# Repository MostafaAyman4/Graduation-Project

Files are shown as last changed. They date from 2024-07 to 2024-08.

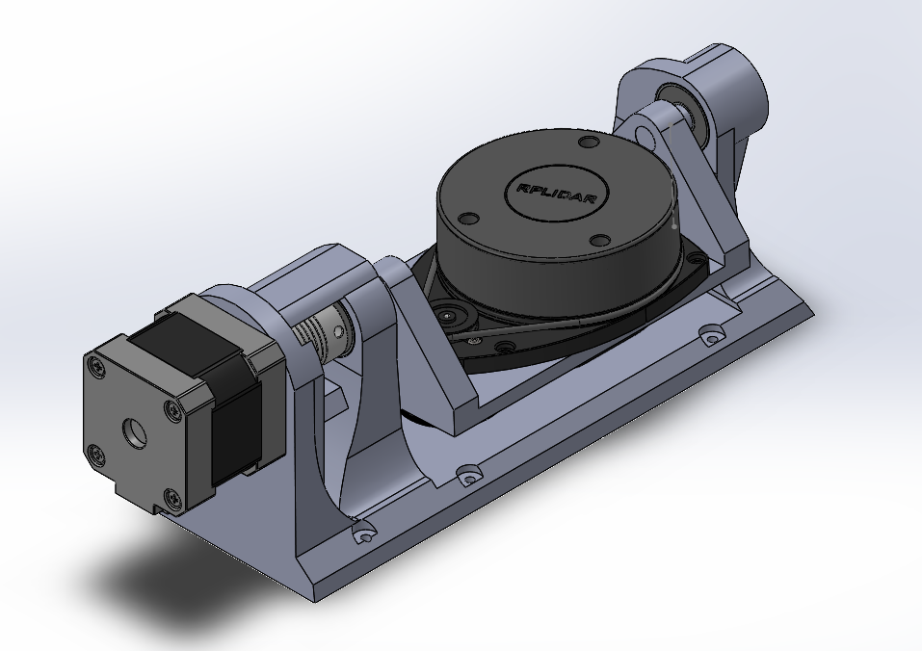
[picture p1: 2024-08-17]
3D designing/3D Lidar/Photos/ASSEMBLY_3D_LIDAR.png

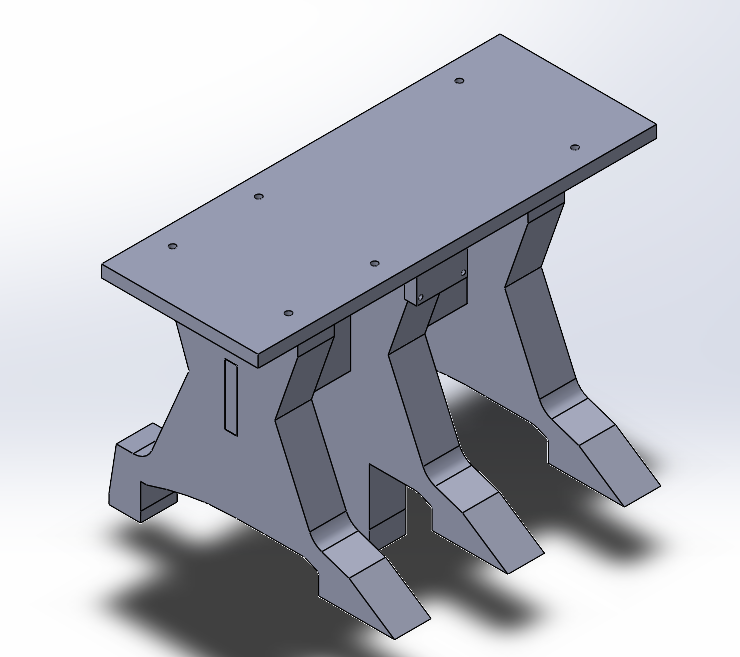
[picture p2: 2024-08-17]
3D designing/3D Lidar Support/Photos/ASSEMBLY_LIDAR_SUPPORT.png

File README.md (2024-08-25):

# Self-Driving Car
/*******************************************************************************************

************************** THIS REPO CONTAINS ONLY MY PARTS *************************

********************************************************************************************/

We have achieved Level 3 on the automotive scale, having successfully passed the first four levels test stages:



Level 0: A pretty simple phase where we manually controlled the car using a mobile application.

Level 1: Implemented an anti-collision using ultrasonic sensors System to monitor the surrounding environment.

Level 2: The car began to take control of its speed and direction autonomously, implementing lane assistance.

Level 3: The car can now drive itself entirely, determining its destination from the user’s application and using built-in GPS for navigation. It processes a significant amount of data to drive autonomously.

Project Specializations :

Project diagram

 1. Embedded systems
 2. AI
 3. Circuit design
 4. PCB design and manufacturing
 5. 3D design

-I was responsible for these parts

    •	Project architecture
   
    •	All ARM (M3) cores connected together with CAN bus
   
       1.	Motion layer (back motors and steering system with PID controller)
       
       2.	Mapping layer (8 ultrasonic sensor runs 4 by 4 parallel)
       
       3.	Lidar layer (I transform 2D lidar to Work as 3D lidar by I mechanism and codes with equations)
       
    •	Main core (I wrote the MCAL Layer and collaborated with Nagham and Noran to design the code’s architecture and algorithms)
   
    •	Circuit diagram, PCB design and manufacturing with solder mask
   
    •	3D designing

   -Team Members 
   
     -Mostafa Prince
     
     -Nagham Nasser
     
     -Noran Nabil
     
     -Rodina Mohamed

   ALL DATA IN THIS REPO ARE OPEN SOURCE, FEEL FREE TO USE IT TO SHAPE THE NEW FUTURE
   
   CONTACT ME IF U NEED ANY HELP @ mostafaaymen109@gmail.com

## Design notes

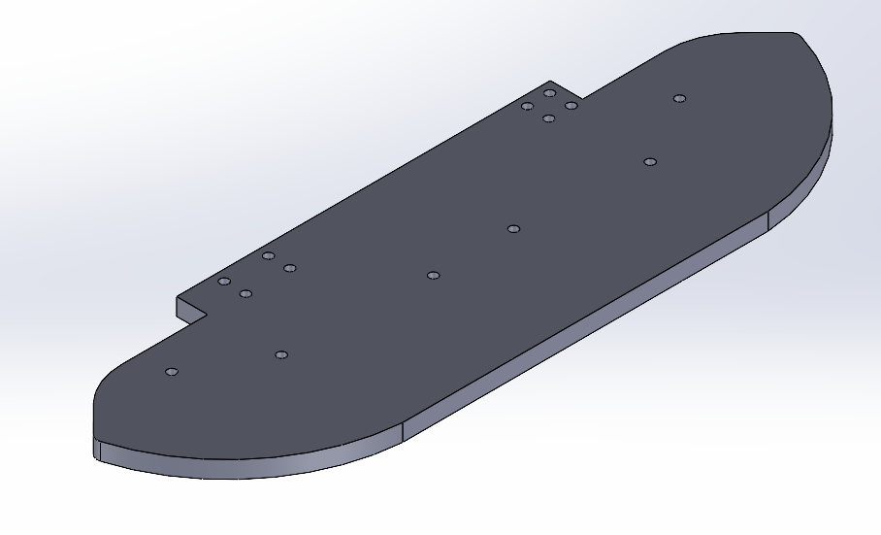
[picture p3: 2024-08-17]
3D designing/Main body/Photos/AS.png

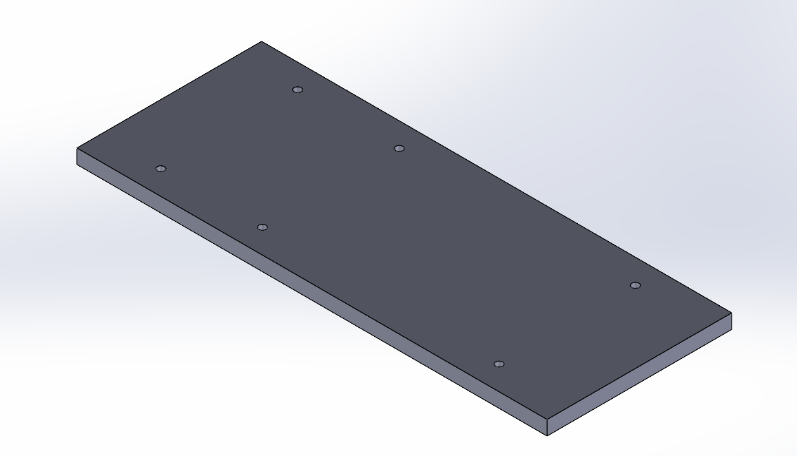
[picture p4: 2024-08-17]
3D designing/3D Lidar Support/Photos/Screenshot 2024-07-12 020455.png

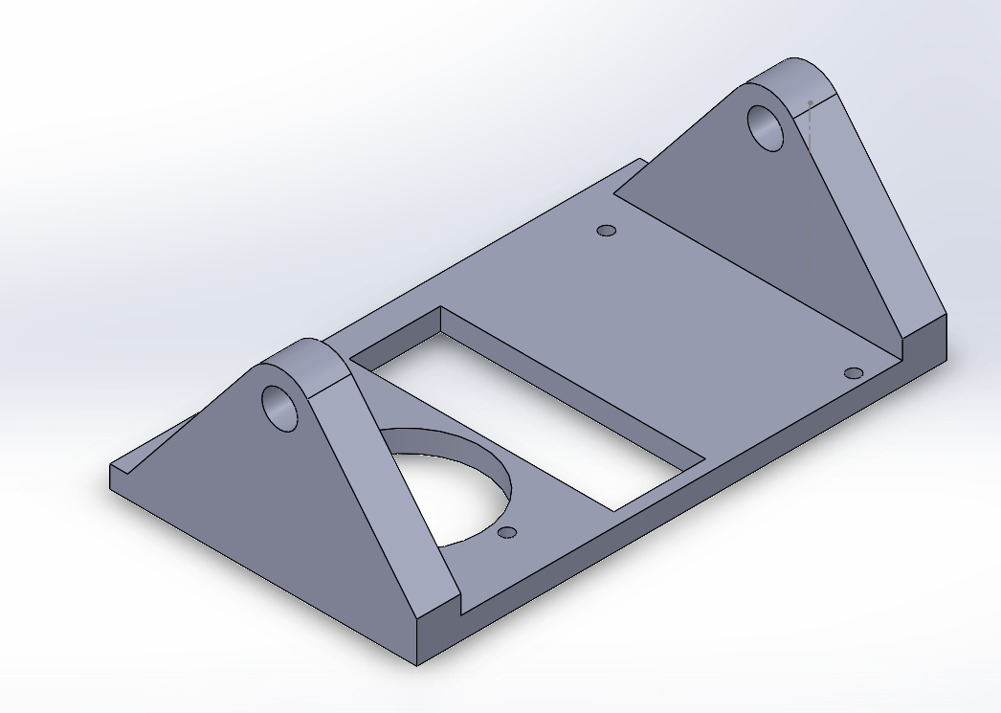
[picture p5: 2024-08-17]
3D designing/3D Lidar/Photos/Screenshot 2024-07-12 014340.png

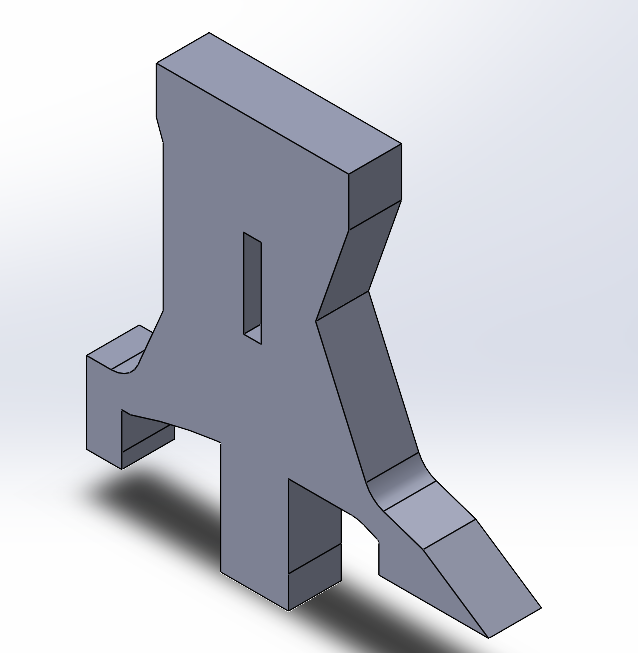
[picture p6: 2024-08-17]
3D designing/3D Lidar Support/Photos/Screenshot 2024-07-12 020410.png

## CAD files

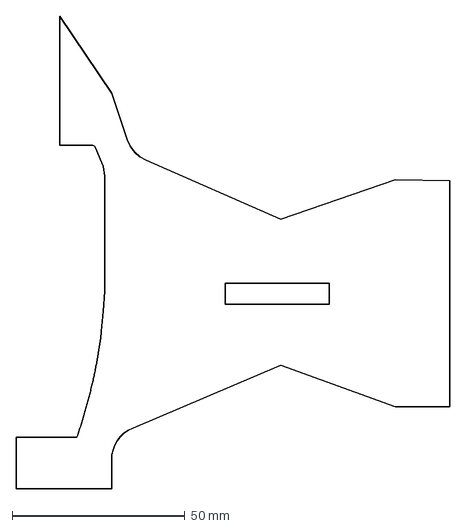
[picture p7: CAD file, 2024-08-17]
3D designing/3D Lidar Support/DXF FILES/LEFT_SUPPORT.dxf
125.6 x 136.9 mm

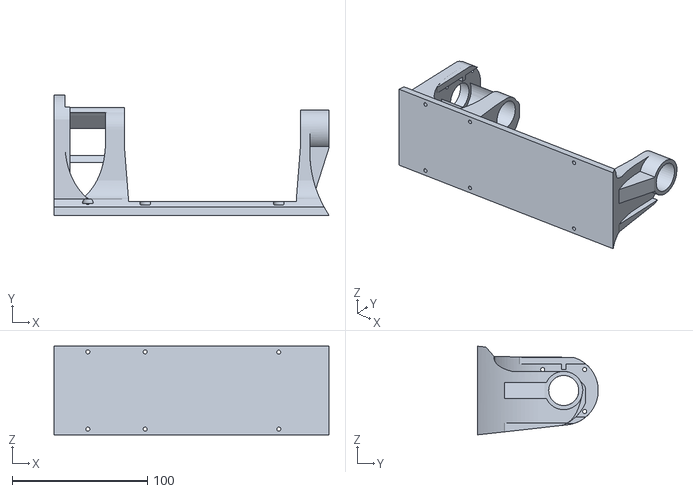
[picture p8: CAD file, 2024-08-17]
3D designing/3D Lidar/PLA Printing/BASE.stl
203.1 x 89.0 x 65.5

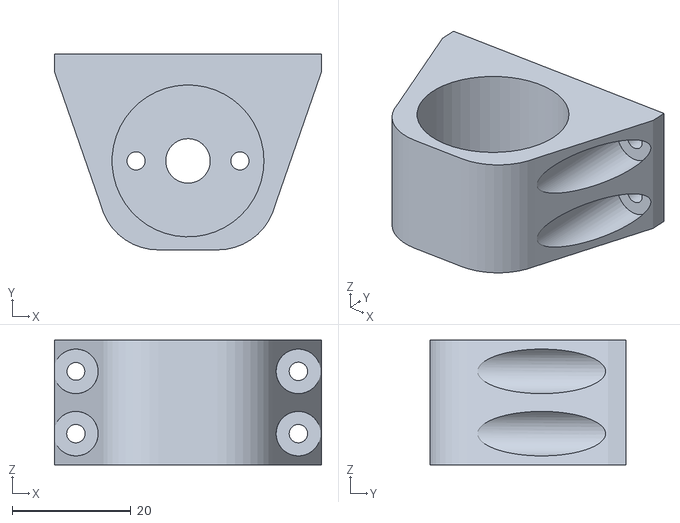
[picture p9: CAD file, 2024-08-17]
3D designing/Back Motors Holder/STL Files/MOTOR_HOLDER--V2.STL
45.0 x 33.0 x 21.0

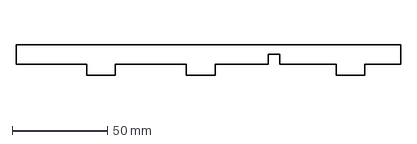
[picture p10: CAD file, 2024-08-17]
3D designing/Main body/DXF files/Supports.dxf
201.4 x 15.8 mm

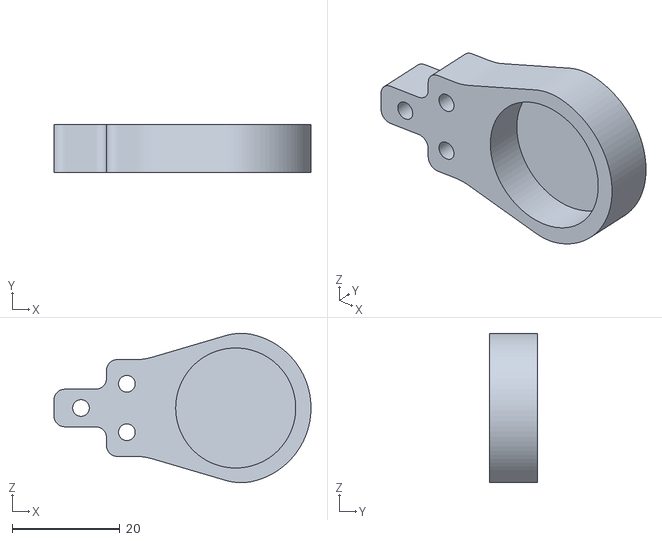
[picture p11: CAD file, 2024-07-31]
3D designing/Steering System/PLA Printing/bearing_support.stl
47.8 x 9.00 x 27.7

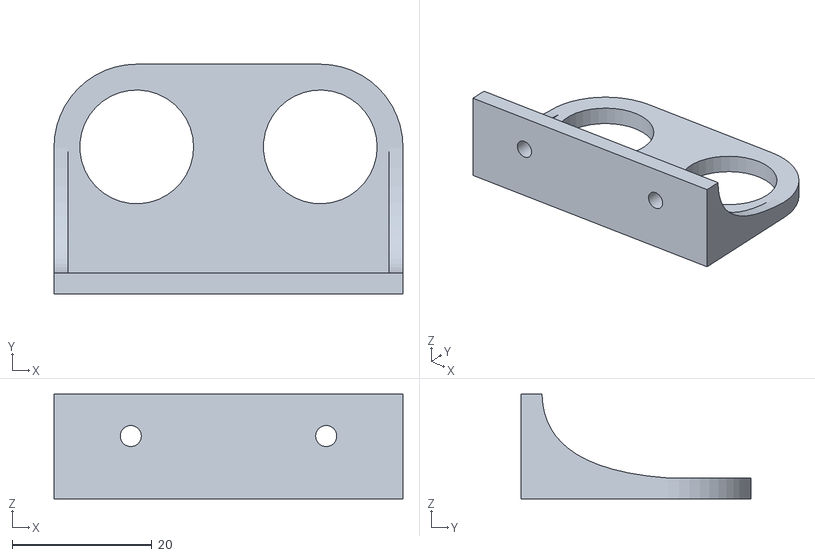
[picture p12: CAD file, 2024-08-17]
3D designing/Ultrasonic Holder/STL Files/ULTRASONIC HOLDER-parody 6 pieces.STL
50.0 x 32.9 x 15.0

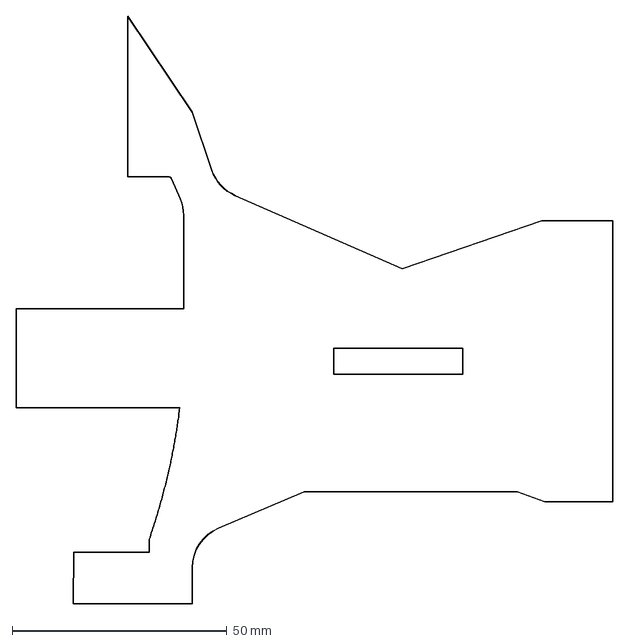
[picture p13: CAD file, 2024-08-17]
3D designing/3D Lidar Support/DXF FILES/Center_support.dxf
139.0 x 136.9 mm

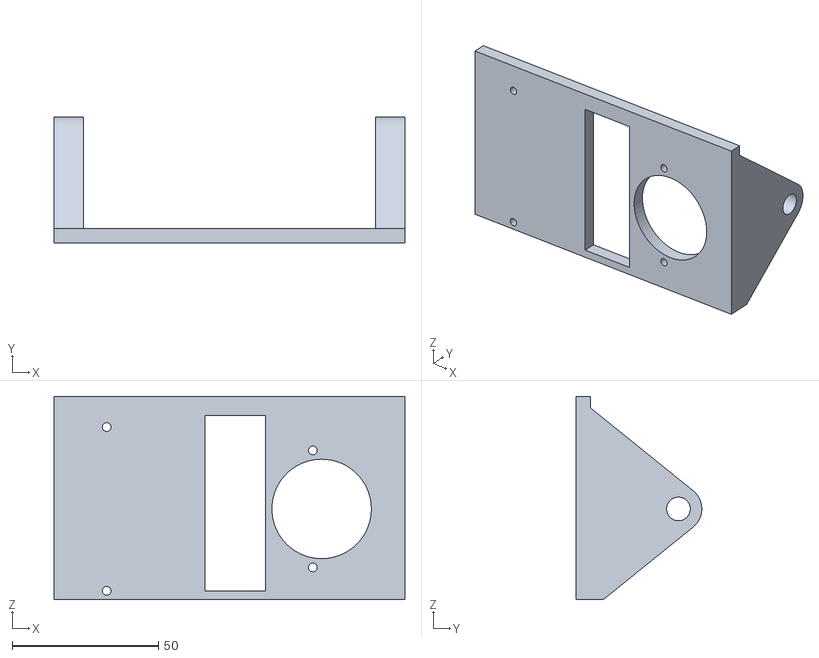
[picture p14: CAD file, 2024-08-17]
3D designing/3D Lidar/PLA Printing/moving part.stl
120.0 x 43.0 x 69.5

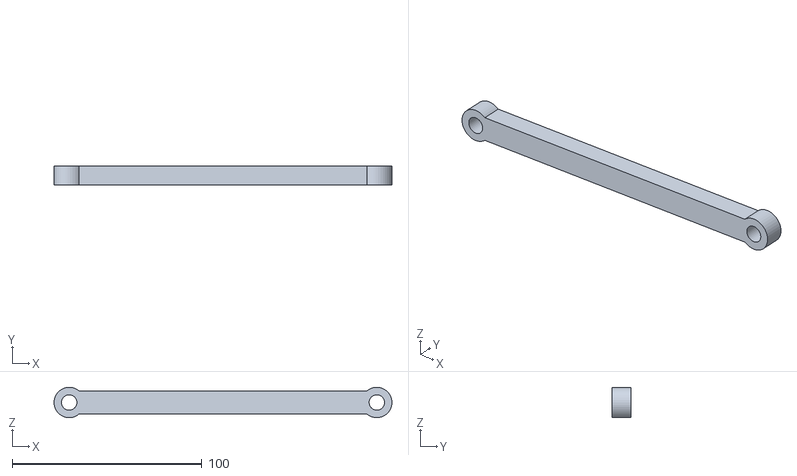
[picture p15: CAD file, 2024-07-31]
3D designing/Steering System/PLA Printing/steering_connector.stl
178.0 x 10.0 x 16.0

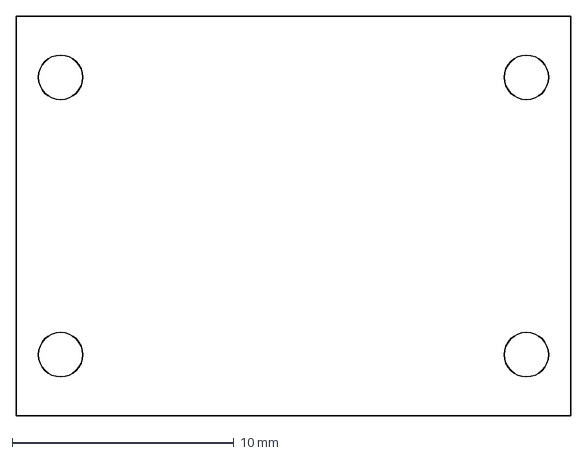
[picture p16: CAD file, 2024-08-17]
3D designing/3D Lidar Support/DXF FILES/Camera_Holder.dxf
25.0 x 18.0 mm

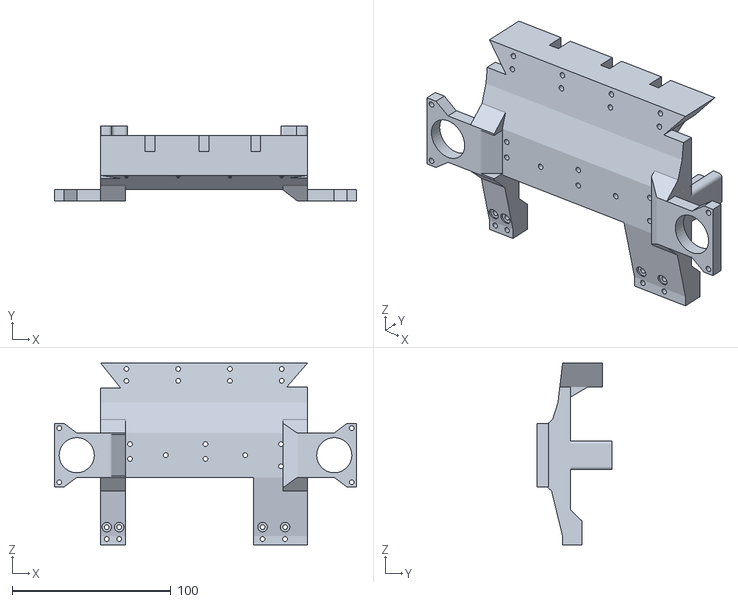
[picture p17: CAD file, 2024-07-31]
3D designing/Steering System/PLA Printing/BASE_V2_top.stl
190.0 x 47.0 x 114.5

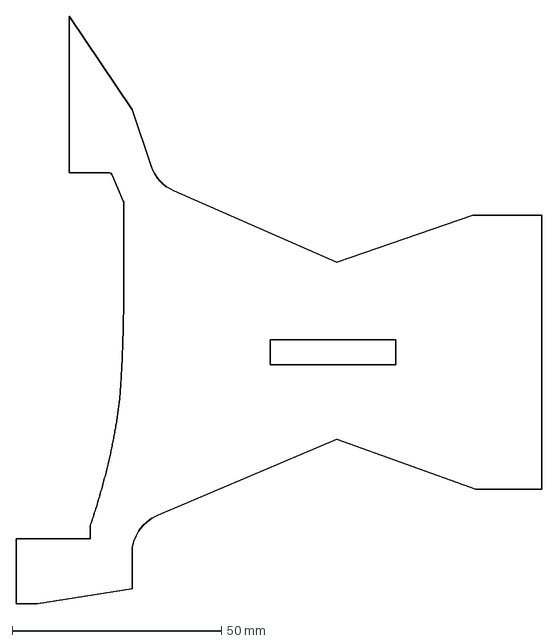
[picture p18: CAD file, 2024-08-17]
3D designing/3D Lidar Support/DXF FILES/RIGHT_SUPPORT.dxf
125.7 x 140.5 mm

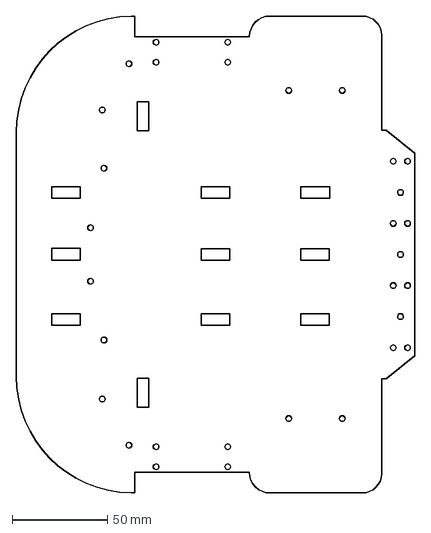
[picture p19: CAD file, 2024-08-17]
3D designing/Main body/DXF files/Base_LASER_CUT_2.dxf
208.9 x 250.0 mm

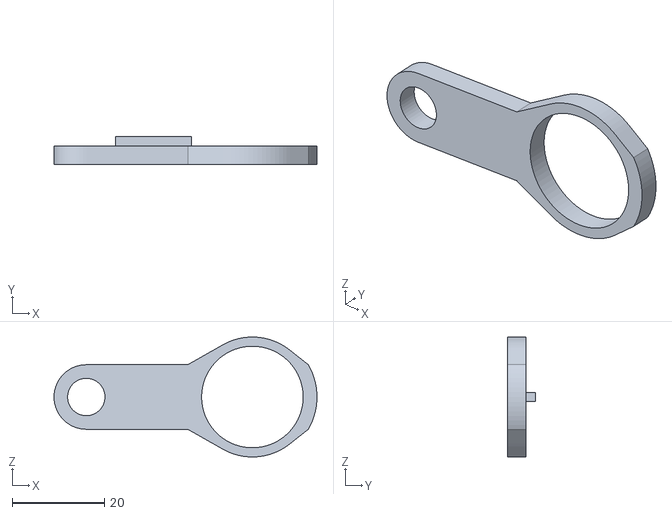
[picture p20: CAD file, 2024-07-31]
3D designing/Steering System/PLA Printing/wheel_connector_half.stl
57.0 x 6.00 x 26.0

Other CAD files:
3D designing/Main body/DXF files/base_laser_cut_1 v1.dxf
3D designing/3D Lidar Support/DXF FILES/Lidar_Base.dxf
3D designing/Main body/DXF files/test_dxf.dxf
3D designing/Steering System/PLA Printing/wheel_connector.stl
3D designing/3D Lidar Support/DXF FILES/Lidar_connector.dxf
3D designing/Main body/DXF files/Support_2.dxf
3D designing/Main body/DXF files/base_laser_cut_1 v0.dxf
3D designing/Steering System/PLA Printing/wheel holder.stl

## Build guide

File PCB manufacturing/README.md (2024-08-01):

# Manufacturing of PCBS with Solder Mask
   IMG_7378 (1)

Printed Circuit Boards (PCBs) are essential components in electronic devices, providing the necessary platform for mounting and connecting electronic components. One of the DIY-friendly methods for PCB manufacturing is the toner transfer method. This repo outlines the process of manufacturing PCBs using the toner transfer technique, highlighting each step involved.
1. Design Preparation

1.1 Schematic Capture

The process begins with designing the circuit schematic using Electronic Design Automation (EDA) software we use EASYEDA. The schematic is a blueprint of the electrical connections and components.
main_Schematic

1.2 Layout Design

The schematic is converted into a PCB layout using the same EDA software. This layout includes the placement of components and routing of copper traces. Once finalized, the layout is printed onto glossy paper or special toner transfer paper using a laser printer.
2. Substrate Preparation

PCB_PCB_Graduation_project_Lega_2_2024-07-15-1

2.1 Cleaning

A copper-clad board, typically made of fiberglass with a layer of copper, is used as the substrate. The copper surface is thoroughly cleaned using fine steel wool or abrasive pads to remove any oxidation and contaminants, ensuring good adhesion of the toner.

3. Toner Transfer
3.1 Aligning and Fixing
The printed design is placed toner-side down onto the cleaned copper-clad board. It is essential to align the design correctly to ensure accurate transfer.



3.2 Toner Transfer
   
Using Toner or Acetone to wet the paper with copper layer and with some pressure the ink stick to the copper
 
3.3 Removing the Paper

the paper is soaked in water to soften it. The paper is then carefully removed, leaving the toner on the copper, which now acts as a resist for the etching process.



4. Etching
   
The board is submerged in an etching solution, typically ferric chloride or ammonium persulfate. The solution removes the exposed copper, leaving only the copper traces protected by the toner. This process is done in a well-ventilated area, using appropriate safety measures.
  


6. Toner Removal
   
After etching, the toner is removed using acetone or isopropyl alcohol, revealing the copper traces that form the circuit.




8. Drilling
A drill press or a handheld drill with fine drill bits is used to create holes for through-hole components and vias. Precision is crucial to ensure proper component placement.

9. Solder Mask Application
Applying a solder mask to a printed circuit board (PCB) is an essential step in ensuring the board’s durability and reliability. A solder mask protects the copper traces from oxidation, prevents solder bridges during soldering, and improves the overall appearance of the PCB. One effective method for applying a solder mask is using a silk screen frame. This report provides a step-by-step guide on how to create and apply a solder mask using this technique.
Materials and Tools Needed
•	Cleaned PCB with exposed copper traces
•	Silk screen frame with fine mesh
•	Solder mask ink (e.g., UV curable or thermal curing solder mask)
•	Squeegee
•	Transparent film with the solder mask pattern (positive or negative image)
•	UV light source (for UV curable masks)
•	Developer solution (if using a photoimageable solder mask)
•	Curing oven (if using thermal curing solder mask)
•	Protective gloves and goggles
•	Isopropyl alcohol or acetone
•	Fine abrasive pad or steel wool (for initial cleaning)
Step-by-Step Process
1. Preparing the PCB
1.	Cleaning: Ensure the PCB is clean and free of any contaminants. Use a fine abrasive pad or steel wool to scrub the copper surface lightly. Clean the board with isopropyl alcohol or acetone and let it dry completely.
2. Preparing the Silk Screen
1.	Design Preparation: Print the solder mask pattern onto a transparent film. This pattern should expose areas where solder will be applied and protect the rest of the board.
 
  


2.	Setting Up the Screen: Attach the transparent film to the silk screen frame. Ensure that the film is aligned correctly with the PCB layout. The screen should have a fine mesh suitable for detailed work.

  


3. Applying the Solder Mask
1.	Applying the Solder Mask Ink: Pour a small amount of solder mask ink onto the silk screen.

  	 

3.	Spreading the Ink: Using a squeegee, spread the solder mask ink evenly across the screen. The ink will pass through the mesh in areas not blocked by the pattern, transferring the solder mask design onto the PCB.



4.	Positioning the PCB: Place the cleaned PCB under the silk screen frame. Ensure it is properly aligned with the pattern on the transparent film.

 

5.	Checking Coverage: Carefully lift the silk screen frame and inspect the PCB to ensure the solder mask has been applied correctly. All areas that need to be protected should be covered with the solder mask ink.
4. Curing the Solder Mask
1.	UV Curable Solder Mask:
o	Exposure: Place the PCB under a UV light source, exposing it for the recommended amount of time specified by the solder mask manufacturer.



o	Developing: If using a photoimageable solder mask, immerse the PCB in the developer solution to remove unexposed areas, revealing the solder mask pattern.
3.	Thermal Curing Solder Mask:
o	Curing: Place the PCB in a curing oven and bake it at the temperature and duration specified by the solder mask manufacturer.
5. Final Inspection and Touch-Up
1.	Inspection: Inspect the cured solder mask for any defects or areas where coverage is inadequate. Use a magnifying glass or microscope for detailed inspection.  
2.	Touch-Up: If necessary, use a small brush to apply additional solder mask ink to any missed spots and cure as needed.
6. Cleaning and Finishing
1.	Cleaning: Clean the PCB with isopropyl alcohol or acetone to remove any residual developer or uncured ink.
2.	Finishing: Lightly sand the solder mask surface to smooth out any rough edges or uneven areas.

8. Assembly
8.1 Component Placement
Components are manually placed on the board according to the design. 
8.2 Soldering
Components are soldered using a soldering iron. For SMD components, a reflow oven or hot air gun may be used to melt solder paste applied during placement.



9. Testing and Inspection

9.1 Visual Inspection
A through visual inspection is conducted to check for any visible defects such as solder bridges, misaligned components, or incomplete etching.

9.2 Electrical Testing
Basic electrical tests are performed to ensure continuity and correct connections. Multimeters or simple test circuits can be used to verify functionality.
 


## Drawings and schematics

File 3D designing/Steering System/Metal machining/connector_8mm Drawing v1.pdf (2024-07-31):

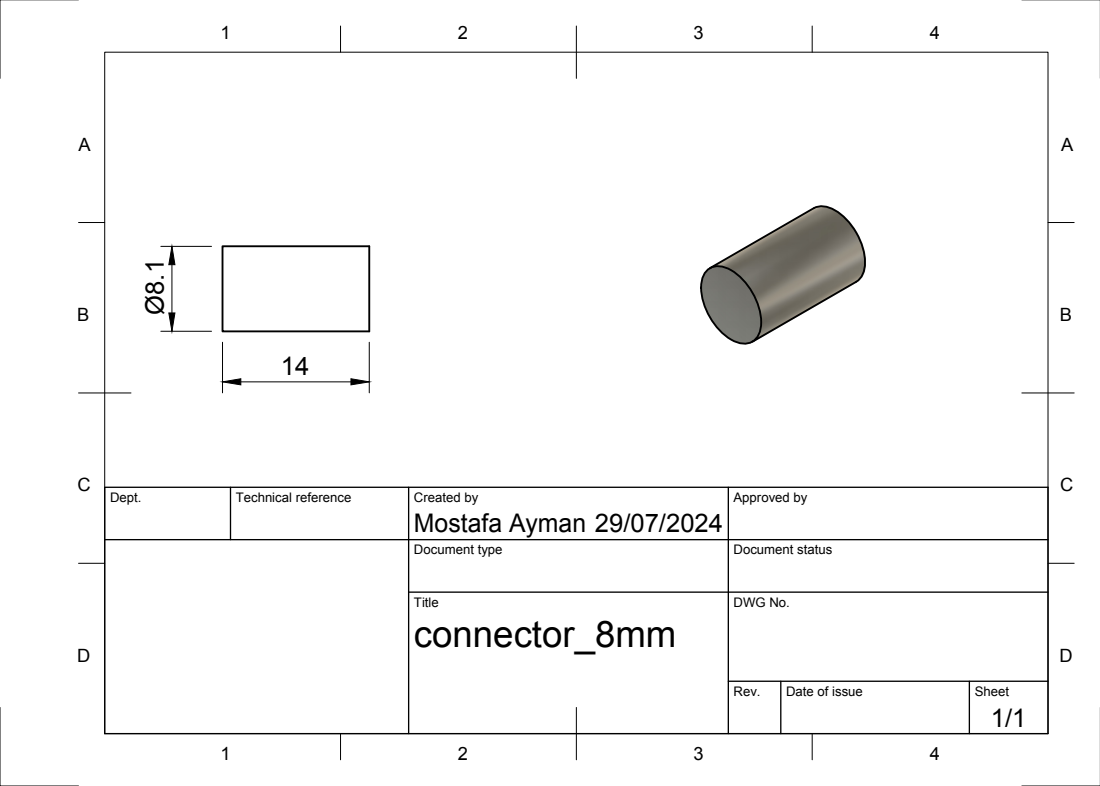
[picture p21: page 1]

Dept. | Technical reference | Created by Mostafa Ayman 29/07/2024 | Approved by

Document type | Document status

Title connector_8mm | DWG No.

Rev. | Date of issue | Sheet 1/1

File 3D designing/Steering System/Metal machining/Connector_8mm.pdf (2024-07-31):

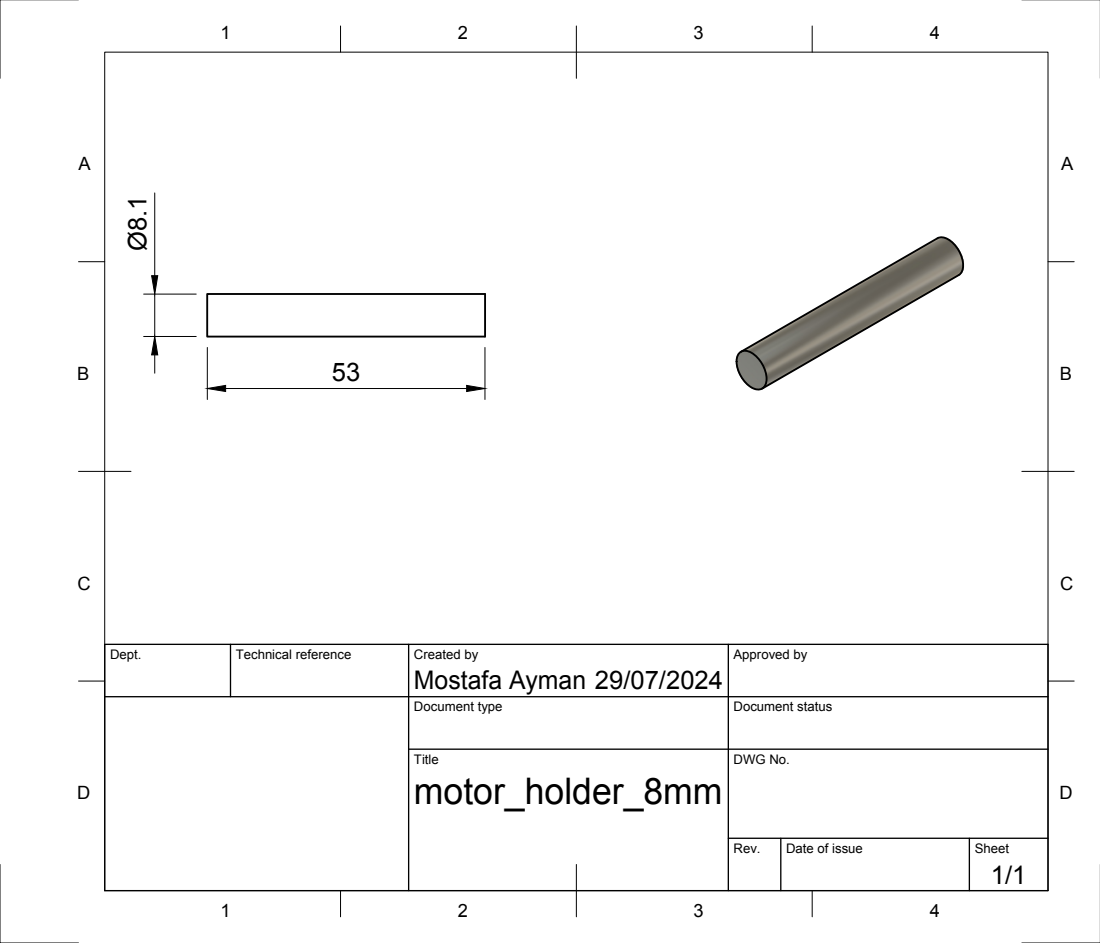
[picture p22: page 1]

Dept. | Technical reference | Created by Mostafa Ayman 29/07/2024 | Approved by

Document type | Document status

Title motor_holder_8mm | DWG No.

Rev. | Date of issue | Sheet 1/1

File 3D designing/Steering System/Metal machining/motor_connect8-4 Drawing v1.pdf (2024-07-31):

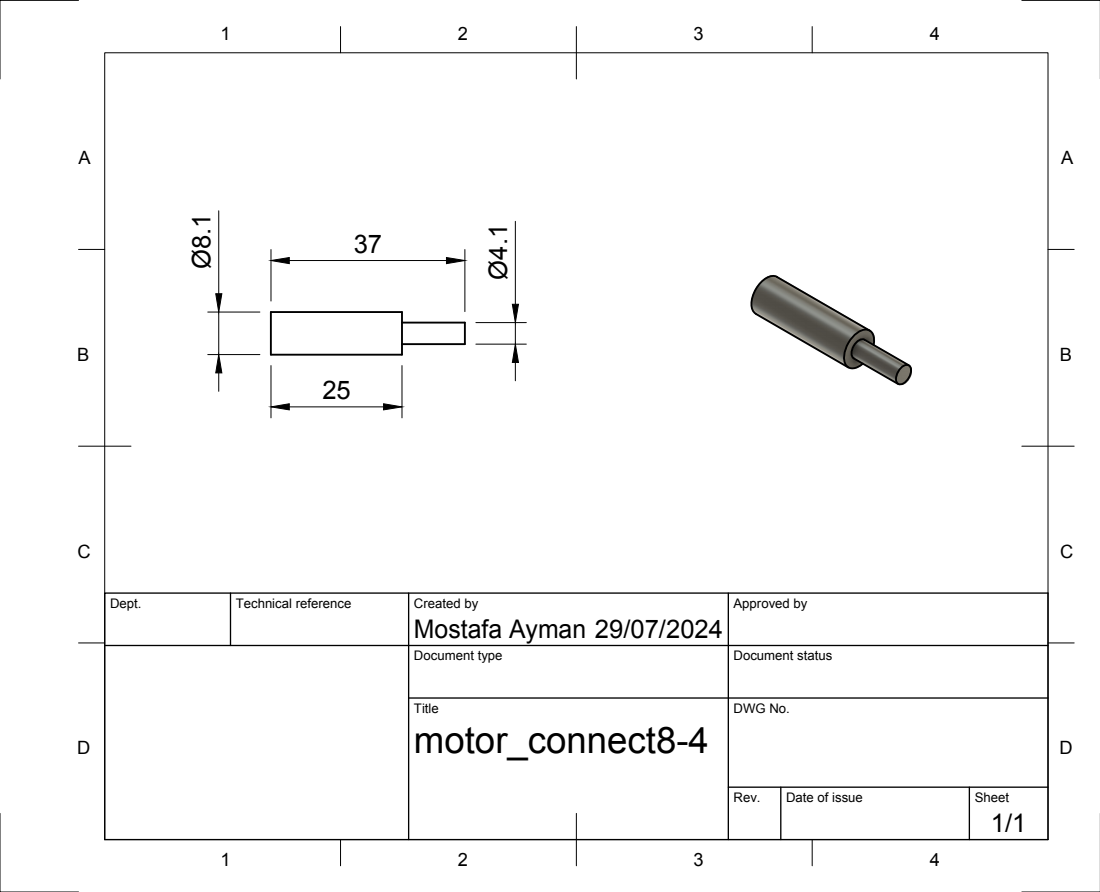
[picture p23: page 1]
Mostafa Ayman Ø8.1

Dept. | Technical reference | Created by 29/07/2024 | Approved by

Document type | Document status

Title motor_connect8-4 | DWG No.

Rev. | Date of issue | Sheet 1/1

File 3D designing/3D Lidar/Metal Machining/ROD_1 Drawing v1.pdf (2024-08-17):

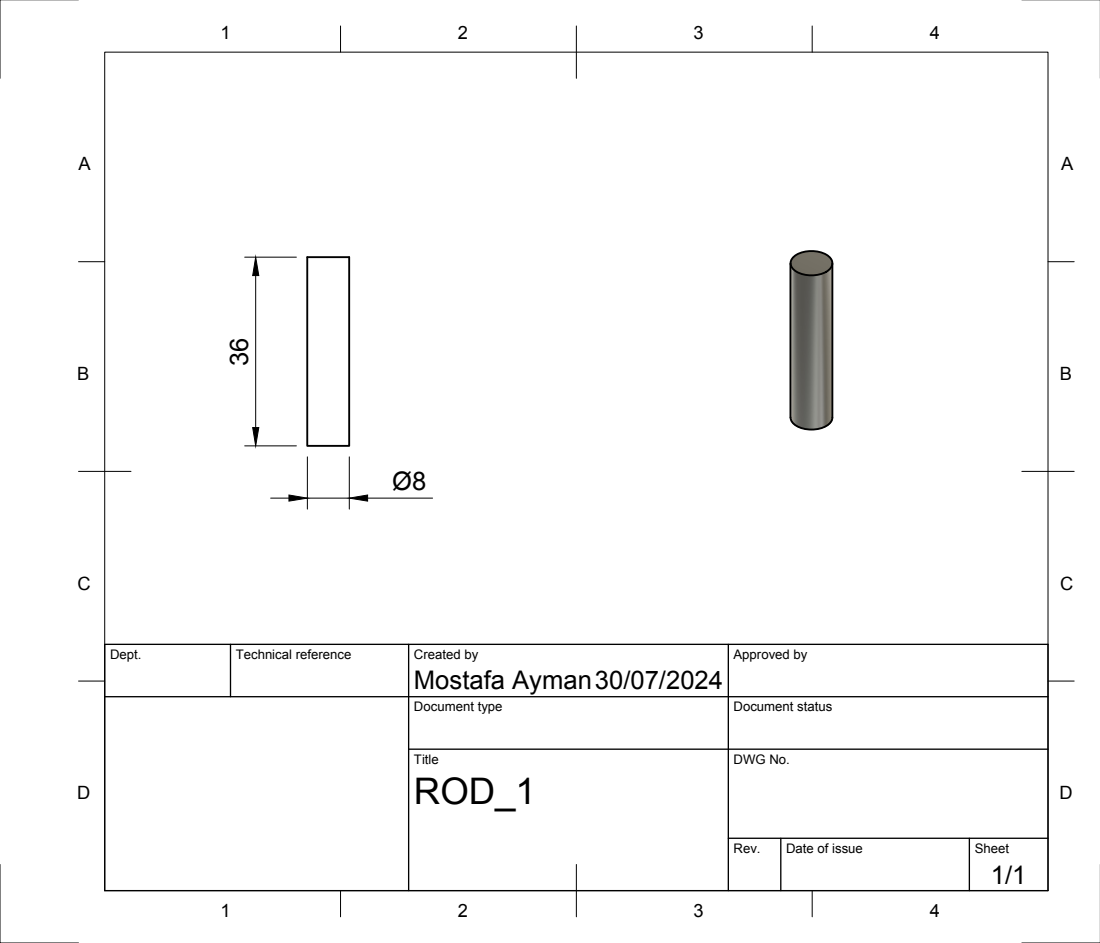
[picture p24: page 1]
Mostafa Ayman 36

Dept. | Technical reference | Created by 30/07/2024 | Approved by

Document type | Document status

Title ROD_1 | DWG No.

Rev. | Date of issue | Sheet 1/1

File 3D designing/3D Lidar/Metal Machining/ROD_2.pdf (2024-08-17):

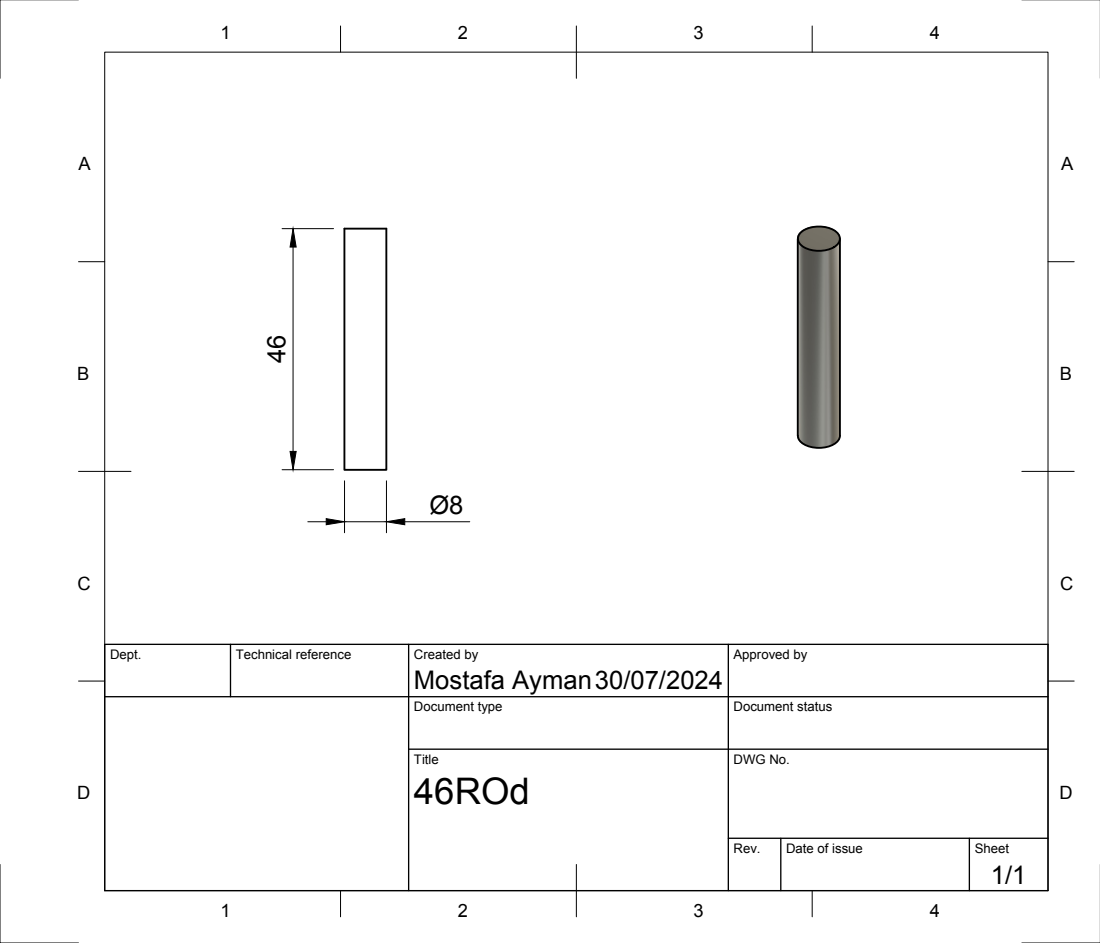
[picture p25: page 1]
Mostafa Ayman 46

Dept. | Technical reference | Created by 30/07/2024 | Approved by

Document type | Document status

Title 46ROd | DWG No.

Rev. | Date of issue | Sheet 1/1

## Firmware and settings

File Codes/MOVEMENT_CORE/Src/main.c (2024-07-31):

/*
 * @file   		main.c
 * @author 		Mostafa Ayman
 * @version		V4.0
 * @MC          STM32F103x
 * @brief       this file has the main program for the motors layer
 */

#include <math.h>
#include "../Inc/LIB/STD_TYPES.h"
#include "../Inc/LIB/BIT_MATH.h"
#include "../Inc/MCAL/RCC/RCC_interface.h"

//#include "../Inc/MCAL/RCC/RCC_private.h"
#include "../Inc/MCAL/DIO/DIO_interface.h"
#include "../Inc/MCAL/SYSTIC/MSYSTICK_interface.h"
#include "../Inc/MCAL/STK/STK_interface.h"

#include "../Inc/MCAL/USART/UART_interface.h"
#include "../Inc/MCAL/CAN/CAN_interface.h"
#include "../Inc/MCAl/GENERAL_PURPOSE_TIMERS/GENRERALTIMERS_interface.h"
//#include "../Inc/MCAl/GENERAL_PURPOSE_TIMERS/GENRERALTIMERS_private.h"
#include "../Inc/MCAL/NVIC/MNVIC_interface.h"

//#include "../Inc/HAL/ULTRASONIC/ULTRASONIC_interface.h"
//#include "../Inc/HAL/ULTRASONIC/ULTRASONIC_config.h"

#include "../Inc/HAL/BACK_MOTORS/BKMOTORS_interface.h"
#include "../Inc/MCAL/EXTI/EXTI_interface.h"
#include "../Inc/HAL/SERVO/SERVO_interface.h"
#if !defined(_SOFT_FP_) && defined(__ARM_FP)
  #warning "FPU is not initialized, but the project is compiling for an FPU. Please initialize the FPU before use."
#endif
/**************************************************************
 * ************ * Macros* ************************
 **************************************************************/
#define TX_PIN			10
#define RX_PIN			11

#define MOTOR_ENCODER_PIN  PA0
///////////////////used in motor movement///////////////////////
#define FORWARD       2
#define BACKWARD      3

#define speed_level_1        130
#define speed_level_2        170
#define speed_level_3		 210
#define speed_level_4		 255

/**************************************************************
 * ************ * Variables* ************************
 **************************************************************/
float init_time=0;
float final_time=0;
float duration_time=0;
float freq;
float average=0;
int index=0;
float deltaT=0;
float v1Filt = 0;
float v1Prev = 0;
float eintegral = 0;
float kp = 4;
float ki = 50;
int desired_speed=100;
int pwr=255;
volatile uint32 DIS_TOTAL_PULSES =0;
volatile long double desired_distance=0;
volatile long double Distance=0;
volatile uint8 move_flag =0;
volatile int counter_pulses=0;

/////////////////can variables/////////////////////////////
uint8 GLOBAL_CAN_data_RX[8];

////////////////back motors variables//////////////////////
uint8 GLOBAL_MOTOR_SPEED_LOOKUP_T[4]={speed_level_1,speed_level_2,speed_level_3,speed_level_4};

///////////////Servo variables/////////////////////////////
uint8 GLOBAL_Servo_angles_LOOKUP_T[7] ={0,30,60,90,120,150,180};

/**************************************************************
 * ************ * function definition* ************************
 **************************************************************/
void CAN_TX(void);
void CAN_RX(void);
uint16 Std_id_High(uint16 local_u16Std_Id);
void CAN_FilterConfig(void);
void CAN_TxMailbox0CompleteCallback();
void CAN_RxFifo0MsgPendingCallback();

double convertAToB(double A);
void speed_measure(void);
void PID_controller_Velocity(void);
void move_distance(long double copy_float64dis,uint8 copy_uint8Direction,uint8 copy_uint8speed);
void Encoder_INT_POSITION(void);
void Encoder_INT_SPEED(void);
void BACK_MOTORS_INIT(void);
void BACK_MOTORS_MOVE(uint8 copy_uint8_M_R_speed,uint8 copy_uint8_M_L_speed,uint8 copy_uint8_M_R_DIR, uint8 copy_uint8_M_L_DIR);
void BACK_MOTORS_STOP(void);
/**************************************************************
 * ************ * main function* ************************
 **************************************************************/
int main(void)
{
	MRCC_voidInitClock();

	MRCC_voidEnableClock(RCC_APB1,UASRT3_EN);
	MUSART_voidInit(USART_3);
	MDIO_INIT(PORTA);
	MDIO_INIT(PORTB);
	MEXTI_voidInit(MOTOR_ENCODER_PIN,RISING_ENGE);
	MEXTI_voidSetCallback(0,Encoder_INT_POSITION);


	MDIO_voidSetDirection(PORTA,MOTOR_ENCODER_PIN, INPUT_FLOATING);
	//INPUT_PULL_DOWN

	MDIO_voidSetDirection(PORTB ,TX_PIN ,AF_2MHZ_PUSH_PULL);
	MDIO_voidSetDirection(PORTB ,RX_PIN ,INPUT_FLOATING);
	MDIO_voidSetDirection(PORTB,0, OUTPUT_10MHZ_PUSH_PULL);
	MDIO_voidWrite_D_pin(PORTB,0,HIGH);

	/************************
	 * can initiation
	 * /* CAN init */
	CAN_voidInit();
	/* CAN Filter set */
	CAN_FilterConfig();
	//CAN_Interrupt();
	/* CAN Start */
	CAN_voidStart();

	MUSART_voidSendWord(USART_3,"node start\n");

	//MEXTI_voidInit(PA6,RISING_ENGE);
	HBKMOTORS_voidinit(MOTOR_LEFT);
	//HBMOTORS_voidSetSpeed(MOTOR_LEFT,255);


	//MSYSTICK_voidInit();
	//STK_voidInit();
	//STK_voidStartMicros();

	//MEXTI_voidEnable(MOTOR_ENCODER_PIN);
	//move_distance(0.20420352248,RIGHT,255);
	//HBKMOTORS_voidRUN(MOTOR_LEFT,RIGHT);
	BACK_MOTORS_INIT();
	HSERVO_VOIDINIT();
	//BACK_MOTORS_MOVE(125,125,FORWARD, FORWARD);
	for(;;){
		CAN_RX();
		MUSART_voidSendWord(USART_3,"CAN FINISH\n");
		if(GLOBAL_CAN_data_RX[0]=='A'){
			HSERVO_VOID_SETANGLE(GLOBAL_Servo_angles_LOOKUP_T[GLOBAL_CAN_data_RX[1]]);
			BACK_MOTORS_MOVE(GLOBAL_CAN_data_RX[2],GLOBAL_CAN_data_RX[2],GLOBAL_CAN_data_RX[4],GLOBAL_CAN_data_RX[4]);
			MUSART_voidSendWord(USART_3,"CAN RECEIVE A \n");
			MUSART_voidSendByte(USART_3,GLOBAL_CAN_data_RX[0]);
			MUSART_voidSendByte(USART_3,'-');
			MUSART_voidSendInt(USART_3,GLOBAL_Servo_angles_LOOKUP_T[GLOBAL_CAN_data_RX[1]]);
			MUSART_voidSendByte(USART_3,'-');
			MUSART_voidSendInt(USART_3,GLOBAL_CAN_data_RX[4]);
			MUSART_voidSendByte(USART_3,'-');
			MUSART_voidSendInt(USART_3,GLOBAL_CAN_data_RX[2]);
			MUSART_voidSendByte(USART_3,'\n');
		}



		/****************
		 * can send and receive
		 * CAN_TX();
    		//CAN_RX();
		 */
		//MEXTI_voidEnable(MOTOR_ENCODER_PIN);
		//speed_measure();
		//PID_controller_Velocity();


		//STK_voidDelay_ms(500);
		//MEXTI_voidEnable(PA6);
		//MEXTI_voiddisable(PA6);
		//MUSART_voidSendInt(USART_1,counter);
		//counter=0;
	}
}
/**************************************************************
 * ************ * function declaration * **********************
 **************************************************************/
void CAN_TX(void)
{
	CAN_TxHeaderTypeDef tx_header;
	tx_header.StdId = 0x6;
	tx_header.IDE = CAN_ID_STD;
	tx_header.RTR = CAN_RTR_DATA;
	tx_header.DLC = 8;
	tx_header.TransmitGlobalTime=DISABLE;
	uint8 DATA[5] = {'N','O','D','E'};

	CAN_TxHeaderTypeDef tx_header1;
	tx_header1.StdId = 0x7;
	tx_header1.IDE = CAN_ID_STD;
	tx_header1.RTR = CAN_RTR_DATA;
	tx_header1.DLC = 8;
	uint8 DATA1[6] = {'T','W','O'};

	CAN_voidAddTxMsg(&tx_header,DATA);
	CAN_voidAddTxMsg(&tx_header1,DATA1);
}
void CAN_RX(void)
{
	MUSART_voidSendWord(USART_3, "/////////////");
	CAN_RxHeaderTypeDef Rx_header;
	while(CAN_voidRXPending(CAN_RX_FIFO0) == 0);
	//MUSART_voidSendInt(USART_3,Rx_header.StdId);

	CAN_voidGetRxMsg(CAN_RX_FIFO0,&Rx_header,GLOBAL_CAN_data_RX);
	/*MUSART_voidSendByte(USART_3,GLOBAL_CAN_data_RX[0]);
	MUSART_voidSendByte(USART_3,'-');
	MUSART_voidSendInt(USART_3,GLOBAL_Servo_angles_LOOKUP_T[GLOBAL_CAN_data_RX[1]]);
	MUSART_voidSendByte(USART_3,'-');
	MUSART_voidSendInt(USART_3,GLOBAL_CAN_data_RX[4]);
	MUSART_voidSendByte(USART_3,'-');
	MUSART_voidSendInt(USART_3,GLOBAL_CAN_data_RX[2]);
	MUSART_voidSendByte(USART_3,'\n');
*/
	//MUSART_voidSendWord(USART_3, GLOBAL_CAN_data_RX);
	//MUSART_voidSendWord(USART_3, "\n");
}
uint16 Std_id_High(uint16 local_u16Std_Id)
{
	return (local_u16Std_Id << 5);
}
void CAN_FilterConfig(void)
{
	CAN_FilterTypeDef CAN_FilterInit;
	CAN_FilterInit.FilterActivation = ENABLE;
	CAN_FilterInit.FilterBank = 0;
	CAN_FilterInit.FilterFIFOAssignment = CAN_FILTER_FIFO0;
	CAN_FilterInit.FilterIdHigh = Std_id_High(0x65d);
	CAN_FilterInit.FilterIdLow = 0x0000;
	CAN_FilterInit.FilterMaskIdHigh = 0x0000;
	CAN_FilterInit.FilterMaskIdLow = 0x0000;
	CAN_FilterInit.FilterMode = CAN_FILTERMODE_IDMASK;
	CAN_FilterInit.FilterScale = CAN_FILTERSCALE_32BIT;

	CAN_voidConfigFilter(&CAN_FilterInit);
}
/*
void CAN_Interrupt(void)
{
	CAN_voidInitInterput(CAN_TX_IRQn);
	CAN_voidInitInterput(CAN_RX0_IRQn);
	CAN_voidInitInterput(CAN_RX1_IRQn);
	CAN_voidInitInterput(CAN_SCE_IRQn);

	CAN_voidEnableInterrupt(CAN_IER_TX_MAILBOX_EMPTY | CAN_IER_RX_FIFO0_MSG_PENDING | CAN_IER_ERROR | CAN_IER_LAST_ERROR_CODE | CAN_IER_BUSOFF);
}
*/
void CAN_TxMailbox0CompleteCallback()
{
	/* print MSG on UART1 */
	char MSG[50] = " MSG TRANSMITED m0 \n";
	MUSART_voidSendWord(USART_1, MSG);
	//NVIC_voidSetPendingFlag(CAN_TX_IRQn);
}
void CAN_RxFifo0MsgPendingCallback()
{
	CAN_RX();
	//NVIC_voidSetPendingFlag(CAN_RX0_IRQn);
}
/*
void CAN_ErrorCallback()
{
	/* print MSG on UART1 */
	/*char MSG[50] = "Error Code \n";
	u32 x= CAN_voidGetErrorCode();
	MUSART_voidSendInt(USART_1,&x);
	MUSART_voidSendWord(USART_1, "\n");

}
*/
double convertAToB(double A) {
    // Coefficients of the quadratic equation
    double a = -6.47e-4;
    double b = 0.98;
    double c = 0.48;

    // Calculate B using the quadratic equation
    double B = a * A * A + b * A + c;
    return B;
}
void speed_measure(void){
	average=0;
	while(index<1){

			if(MDIO_uint8Read_D_pin(PORTA,MOTOR_ENCODER_PIN)==1){
			  init_time=Micros();
			  while(MDIO_uint8Read_D_pin(PORTA,MOTOR_ENCODER_PIN)==1);
			  while(MDIO_uint8Read_D_pin(PORTA,MOTOR_ENCODER_PIN)==0);
			  final_time=Micros();
			  duration_time=(final_time-init_time);
			  deltaT = (float)duration_time*0.000001;
			  freq=(1.0/((float)duration_time*0.000001)*60.0)/(458);
			  average+=freq;
			  index++;
			}

			}
			average =average;
			average=convertAToB(average);
			/*if(average==desired_speed){

			}
			else if(average<desired_speed){
				pwr++;
			}
			else if(average>desired_speed){
				pwr--;
			}
			if(pwr<0){
				pwr=0;
			}
			else if (pwr>255){
				pwr=255;
			}*/
			   //HBMOTORS_voidSetSpeed(MOTOR_LEFT,pwr);
			   //MUSART_voidSendInt(USART_3,desired_speed);
			   //MUSART_voidSendByte(USART_3,' ');
			   //MUSART_voidSendInt(USART_3,average);
			   //MUSART_voidSendByte(USART_3,'\n');

			index=0;

}
void PID_controller_Velocity(void){

	float v1 = average;
	 v1Filt = 0.854*v1Filt + 0.0728*v1 + 0.0728*v1Prev;
	 v1Prev = v1;
	 float vt = desired_speed;
	 // Compute the control signal u

	   float e = vt-v1Filt;
	   eintegral = eintegral + e*deltaT;

	   float u = kp*e + ki*eintegral;
	   // Set the motor speed and direction

	   int pwr = (int) fabs(u);
	   HBMOTORS_voidSetSpeed(MOTOR_LEFT,pwr);
		//MUSART_voidSendInt(USART_3,desired_speed);
		//MUSART_voidSendByte(USART_3,' ');
		//MUSART_voidSendInt(USART_3,average);
		//MUSART_voidSendByte(USART_3,'\n');
}
void move_distance(long double copy_float64dis,uint8 copy_uint8Direction,uint8 copy_uint8speed){

	desired_distance= Distance+copy_float64dis;
	move_flag =1;
	//run motor just to start interrupt
	HBMOTORS_voidSetSpeed(MOTOR_LEFT,copy_uint8speed);
	HBKMOTORS_voidRUN(MOTOR_LEFT,copy_uint8Direction);

}

void Encoder_INT_POSITION(void){
	/*counter_pulses++;
	if(counter_pulses >= 458){
		HBKMOTORS_voidSTOP(MOTOR_LEFT);
		MUSART_voidSendInt(USART_3,counter_pulses);
	}*/

	if(Distance>=desired_distance){
		HBKMOTORS_voidSTOP(MOTOR_LEFT);
		move_flag =0;
	}
	else{
	move_flag =1;
	DIS_TOTAL_PULSES++;
	Distance = (long double)DIS_TOTAL_PULSES * 0.00044585922;
	//MUSART_voidSendByte(USART_3,'H');
	//MUSART_voidSendByte(USART_3,'\n');
	}

}
void Encoder_INT_SPEED(void){

}


void BACK_MOTORS_INIT(void){
	MDIO_INIT(PORTA);
	MDIO_INIT(PORTB);
	HBKMOTORS_voidinit(MOTOR_RIGHT);
	HBKMOTORS_voidinit(MOTOR_LEFT);
}
void BACK_MOTORS_MOVE(uint8 copy_uint8_M_R_speed,uint8 copy_uint8_M_L_speed,uint8 copy_uint8_M_R_DIR, uint8 copy_uint8_M_L_DIR){
	HBKMOTORS_voidRUN(MOTOR_RIGHT,copy_uint8_M_R_DIR);
	HBKMOTORS_voidRUN(MOTOR_LEFT,copy_uint8_M_L_DIR);
	HBMOTORS_voidSetSpeed(MOTOR_RIGHT,copy_uint8_M_R_speed);
	HBMOTORS_voidSetSpeed(MOTOR_LEFT,copy_uint8_M_L_speed);
}
void BACK_MOTORS_STOP(void){
	HBKMOTORS_voidSTOP(MOTOR_RIGHT);
	HBKMOTORS_voidSTOP(MOTOR_LEFT);
}

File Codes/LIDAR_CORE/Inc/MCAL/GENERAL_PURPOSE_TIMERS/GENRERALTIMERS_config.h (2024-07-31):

/***********************************************************/
/*Author      : Mostafa Ayman                              */
/*Date        : 10 SEP 2023                                */
/*Version     : V1.0                                       */
/*MC          : STM32Fxxx                                  */
/***********************************************************/
#ifndef GENRERALTIMERS_CONFIG_H
#define GENRERALTIMERS_CONFIG_H

/* options
    APB1 Frequency*/
#define GENERAL_TIMRS_FREQUENCY          1000000

/* options
            from 1 to 65,535
            16-bit
*/
/*PSC= TIMER2_PRESCALER+1;*/
#define TIMER2_PRESCALER                 7
#define TIMER3_PRESCALER                 7
#define TIMER4_PRESCALER                 7
/* options:
            up
            down  
            */
#define TIMER2_DIRECTION      UP
#define TIMER3_DIRECTION      UP
#define TIMER4_DIRECTION      UP

/*
    options:
        0x0000 -> 0xFFFF*/
/*ARR=PWM2_WIDTH+1*/
#define PWM2_WIDTH                 0xFE
#define PWM3_WIDTH                 0xFE
#define PWM4_WIDTH                 0x4E1F

#define PWM2_CH1_WIDTH             0xFE
#define PWM2_CH2_WIDTH             0xFE
#define PWM2_CH3_WIDTH             0xFE
#define PWM2_CH4_WIDTH             0xFE

#define PWM3_CH1_WIDTH             0xFE
#define PWM3_CH2_WIDTH             0xFE
#define PWM3_CH3_WIDTH             0xFE
#define PWM3_CH4_WIDTH             0xFE

#define PWM4_CH1_WIDTH             0x4E1F
#define PWM4_CH2_WIDTH             0xFE
#define PWM4_CH3_WIDTH             0xFE
#define PWM4_CH4_WIDTH             0xFE

/* options
0000: No filter, sampling is done at fDTS
0001: fSAMPLING=fCK_INT, N=2
0010: fSAMPLING=fCK_INT, N=4
0011: fSAMPLING=fCK_INT, N=8
0100: fSAMPLING=fDTS/2, N=6
0101: fSAMPLING=fDTS/2, N=8
0110: fSAMPLING=fDTS/4, N=6
0111: fSAMPLING=fDTS/4, N=8
1000: fSAMPLING=fDTS/8, N=6
1001: fSAMPLING=fDTS/8, N=8
1010: fSAMPLING=fDTS/16, N=5
1011: fSAMPLING=fDTS/16, N=6
1100: fSAMPLING=fDTS/16, N=8
1101: fSAMPLING=fDTS/32, N=5
1110: fSAMPLING=fDTS/32, N=6
1111: fSAMPLING=fDTS/32, N=8
*/
#define INPUT_CHECK_DURATION            0b0010

/*
    OPTIONS:
            RISING
            FALLING
            */
#define TIMER2_CHANNEL_1_CAPTURE_EDGE  FALLING
#define TIMER2_CHANNEL_2_CAPTURE_EDGE  FALLING
#define TIMER2_CHANNEL_3_CAPTURE_EDGE  FALLING
#define TIMER2_CHANNEL_4_CAPTURE_EDGE  FALLING

#define TIMER3_CHANNEL_1_CAPTURE_EDGE  FALLING
#define TIMER3_CHANNEL_2_CAPTURE_EDGE  FALLING
#define TIMER3_CHANNEL_3_CAPTURE_EDGE  FALLING
#define TIMER3_CHANNEL_4_CAPTURE_EDGE  FALLING

#define TIMER4_CHANNEL_1_CAPTURE_EDGE  RISING
#define TIMER4_CHANNEL_2_CAPTURE_EDGE  RISING
#define TIMER4_CHANNEL_3_CAPTURE_EDGE  RISING
#define TIMER4_CHANNEL_4_CAPTURE_EDGE  RISING
/*
    OPTIONS:
    00: no prescaler, capture is done each time an edge is detected on the capture input
    01: capture is done once every 2 events
    10: capture is done once every 4 events
    11: capture is done once every 8 events
*/
#define INPUT_CAPTURE_CHANNEL_1_PRESCALLER   0b00
#define INPUT_CAPTURE_CHANNEL_2_PRESCALLER   0b00
#define INPUT_CAPTURE_CHANNEL_3_PRESCALLER   0b00
#define INPUT_CAPTURE_CHANNEL_4_PRESCALLER   0b00

/*
 * options:
 * 			ENABLE
 * 			DISABLE
 */
#define TIMER_2_INPULSE_OVERFLOW_INT        DISABLE
#define TIMER_3_INPULSE_OVERFLOW_INT        DISABLE
#define TIMER_4_INPULSE_OVERFLOW_INT        DISABLE

#endif

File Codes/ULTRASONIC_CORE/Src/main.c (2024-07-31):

/*
 * @file   		main.h
 * @author 		Mostafa Ayman
 * @version		V2.0
 * @MC          STM32F103x
 * @brief       this file has the main program for the ultrasonic layer
 */
#include "../Inc/LIB/STD_TYPES.h"
#include "../Inc/LIB/BIT_MATH.h"
#include "../Inc/MCAL/RCC/RCC_interface.h"
#include "../Inc/MCAL/DIO/DIO_interface.h"
#include "../Inc/MCAL/SYSTIC/MSYSTICK_interface.h"
#include "../Inc/MCAL/USART/UART_interface.h"
#include "../Inc/MCAl/GENERAL_PURPOSE_TIMERS/GENRERALTIMERS_interface.h"
#include "../Inc/MCAL/NVIC/MNVIC_interface.h"
#include "../Inc/HAL/ULTRASONIC/ULTRASONIC_interface.h"
#include "../Inc/HAL/ULTRASONIC/ULTRASONIC_config.h"
#include "../Inc/MCAL/AFIO/AFIO_interface.h"
#include "../Inc/MCAL/CAN/CAN_interface.h"

#if !defined(_SOFT_FP_) && defined(__ARM_FP)
  #warning "FPU is not initialized, but the project is compiling for an FPU. Please initialize the FPU before use."
#endif

#define TX_PIN			9
#define RX_PIN			10


#define first_three_ultrsonic_ID     0x51
#define second_three_ultrasonic_ID   0x52
#define third_two_ultrasonic_Id      0x50

#define Tx_header_F_ID  			0x56
#define Tx_header_B_ID				0x57
#define Tx_header_F_R_ID			0x58
#define Tx_header_F_L_ID			0x59
#define Tx_header_B_R_ID			0x60
#define Tx_header_B_L_ID			0x61

#define Tx_header_F_INDEX  			1
#define Tx_header_B_INDEX			2
#define Tx_header_F_R_INDEX			4
#define Tx_header_F_L_INDEX			6
#define Tx_header_B_R_INDEX			3
#define Tx_header_B_L_INDEX			5

#define Tx_header_F_Identifier  			'O'
#define Tx_header_B_Identifier				'Q'
#define Tx_header_F_R_Identifier			'R'
#define Tx_header_F_L_Identifier			'S'
#define Tx_header_B_R_Identifier			'T'
#define Tx_header_B_L_Identifier			'U'



#define CAN_first_three_identifer     'D'
#define CAN_second_three_identifer    'E'
#define CAN_third_two_identifer       'C'


#define   top_ultra_index_H             1
#define   top_ultra_index_L             2
#define   back_ultra_index_H         	3
#define   back_ultra_index_L         	4

#define   top_right_ultra_index_H       1
#define   top_right_ultra_index_L       2
#define   middle_right_ultra_index_H    3
#define   middle_right_ultra_index_L    4
#define   back_right_ultra_index_H      5
#define   back_right_ultra_index_L      6

#define   top_left_ultra_index_H       1
#define   top_left_ultra_index_L       2
#define   middle_left_ultra_index_H    3
#define   middle_left_ultra_index_L    4
#define   back_left_ultra_index_H      5
#define   back_left_ultra_index_L      6

#define   P0_PIN		4
#define   P1_PIN		5
#define   P2_PIN		8
#define   P3_PIN		15

#define   REQ_PINS_PORT 			PORTA


uint32 Local_uint32UltrasonicData[4];
uint32 Copy_uint32DisArray_1[4],Copy_uint32DisArray_2[4];
uint32 Global_ULTRA_8X_DISTANCE[8];

uint8 Global_can_first_three[7];
uint8 global_can_second_three[7];
uint8 global_can_third_two[5];

uint8 GLobal_CAN_Send_DATA_array[7];

uint32 Local_uint32UltrasonicData[4];
uint32 Copy_uint32DisArray[4];

uint8 GLOBAL_REQ_PINS_VALUE=0;

CAN_TxHeaderTypeDef Tx_header_first_three;
CAN_TxHeaderTypeDef Tx_header_second_three;
CAN_TxHeaderTypeDef Tx_header_third_two;

CAN_TxHeaderTypeDef Tx_header_F;
CAN_TxHeaderTypeDef Tx_header_B;
CAN_TxHeaderTypeDef Tx_header_F_R;
CAN_TxHeaderTypeDef Tx_header_F_L;
CAN_TxHeaderTypeDef Tx_header_B_R;
CAN_TxHeaderTypeDef Tx_header_B_L;

/*SEND
(char)((WATER_1_PER)>>8), (char)(WATER_1_PER)
*/
/*RECEIVE
 * ((buf[0]<<8)|buf[1])
 */
/******* CAN Transmit Actual Speed *****************/

void REQ_PIN_init(void){
	MDIO_INIT(PORTA);
	MDIO_voidSetDirection(REQ_PINS_PORT ,P0_PIN ,INPUT_PULL_DOWN);
	MDIO_voidSetDirection(REQ_PINS_PORT ,P1_PIN ,INPUT_PULL_DOWN);
	MDIO_voidSetDirection(REQ_PINS_PORT ,P2_PIN ,INPUT_PULL_DOWN);
	//MDIO_voidSetDirection(REQ_PINS_PORT ,P3_PIN ,INPUT_PULL_DOWN);
	MUSART_voidSendWord(USART_1,"REQ_init");
}
void REQ_PIN_READ(void){
	GLOBAL_REQ_PINS_VALUE=0;
	if(MDIO_uint8Read_D_pin(REQ_PINS_PORT,P0_PIN)==1){
		SET_BIT(GLOBAL_REQ_PINS_VALUE,0);
	}
	if(MDIO_uint8Read_D_pin(REQ_PINS_PORT,P1_PIN)==1){
		SET_BIT(GLOBAL_REQ_PINS_VALUE,1);
	}
	if(MDIO_uint8Read_D_pin(REQ_PINS_PORT,P2_PIN)==1){
		SET_BIT(GLOBAL_REQ_PINS_VALUE,2);
	}
	/*if(MDIO_uint8Read_D_pin(REQ_PINS_PORT,P3_PIN)==1){
		SET_BIT(GLOBAL_REQ_PINS_VALUE,3);
	}*/
	/*
	 MUSART_voidSendWord(USART_1,"REQ_VALUE= ");
	 MUSART_voidSendInt(USART_1,GLOBAL_REQ_PINS_VALUE);
	 MUSART_voidSendWord(USART_1,"\n");
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

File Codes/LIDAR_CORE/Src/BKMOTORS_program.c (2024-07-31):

/***********************************************************/
/*Author      : Mostafa Ayman                              */
/*Date        : 9 DEC 2023                                */
/*Version     : V1.0                                       */
/*MC          : STM32Fxxx                                  */
/***********************************************************/
#include "../Inc/LIB/BIT_MATH.h"
#include "../Inc/LIB/STD_TYPES.h"

#include "../Inc/MCAL/RCC/RCC_interface.h"
#include "../Inc/MCAL/DIO/DIO_interface.h"
#include "../Inc/MCAL/SYSTIC/MSYSTICK_interface.h"
#include "../Inc/MCAl/GENERAL_PURPOSE_TIMERS/GENRERALTIMERS_interface.h"

#include "../Inc/HAL/BACK_MOTORS/BKMOTORS_interface.h"
#include "../Inc/HAL/BACK_MOTORS/BKMOTORS_config.h"
#include "../Inc/HAL/BACK_MOTORS/BKMOTORS_private.h"

void HBKMOTORS_voidinit(uint8 Copy_uint8MotorNO){

	MRCC_voidInitClock();
	MRCC_voidEnableClock(RCC_APB1,TIMER_3);

	MTimer_voidInitMode(TIMER_3,PWM);

	//MRCC_voidEnableClock(RCC_APB1,TIMER_3);
	//MTimer_voidInitInputCapture(TIMER_2,CHANNEL_1);

	//MDIO_voidSetDirection(PORTA,0,INPUT_FLOATING);

	switch(Copy_uint8MotorNO){
	case MOTOR_RIGHT:
		MDIO_INIT(RIGHT_MOTOR_PORT);
		MDIO_voidSetDirection(RIGHT_MOTOR_PORT,RIGHT_MOTOR_A_PIN, OUTPUT_10MHZ_PUSH_PULL);
		MDIO_voidSetDirection(RIGHT_MOTOR_PORT,RIGHT_MOTOR_B_PIN, OUTPUT_10MHZ_PUSH_PULL);
		MDIO_voidSetDirection(PORTA,RIGHT_MOTOR_PWM_PIN, AF_10MHZ_PUSH_PULL);

		break;
	case MOTOR_LEFT:
		MDIO_INIT(LEFT_MOTOR_PORT);
		MDIO_voidSetDirection(LEFT_MOTOR_PORT,LEFT_MOTOR_A_PIN, OUTPUT_10MHZ_PUSH_PULL);
		MDIO_voidSetDirection(LEFT_MOTOR_PORT,LEFT_MOTOR_B_PIN, OUTPUT_10MHZ_PUSH_PULL);
		MDIO_voidSetDirection(PORTA,LEFT_MOTOR_PWM_PIN, AF_10MHZ_PUSH_PULL);
		break;
	}

}
void HBKMOTORS_voidRUN(uint8 Copy_uint8MotorNO,uint8 Copy_uint8MotorDir){
	switch(Copy_uint8MotorNO){

	case MOTOR_RIGHT:

		switch(Copy_uint8MotorDir){
		case RIGHT:
			MDIO_voidWrite_D_pin(RIGHT_MOTOR_PORT,RIGHT_MOTOR_A_PIN,HIGH);
			MDIO_voidWrite_D_pin(RIGHT_MOTOR_PORT,RIGHT_MOTOR_B_PIN,LOW);
			break;
		case LEFT:
			MDIO_voidWrite_D_pin(RIGHT_MOTOR_PORT,RIGHT_MOTOR_A_PIN,LOW);
			MDIO_voidWrite_D_pin(RIGHT_MOTOR_PORT,RIGHT_MOTOR_B_PIN,HIGH);
			break;
		}
		break;

	case MOTOR_LEFT:
		switch(Copy_uint8MotorDir){
				case RIGHT:
					MDIO_voidWrite_D_pin(LEFT_MOTOR_PORT,LEFT_MOTOR_A_PIN,HIGH);
					MDIO_voidWrite_D_pin(LEFT_MOTOR_PORT,LEFT_MOTOR_B_PIN,LOW);
					break;
				case LEFT:
					MDIO_voidWrite_D_pin(LEFT_MOTOR_PORT,LEFT_MOTOR_A_PIN,LOW);
					MDIO_voidWrite_D_pin(LEFT_MOTOR_PORT,LEFT_MOTOR_B_PIN,HIGH);
					break;
				}
		break;
	}

}
void HBKMOTORS_voidSTOP(uint8 Copy_uint8MotorNO){
	switch(Copy_uint8MotorNO){

		case MOTOR_RIGHT:
			MDIO_voidWrite_D_pin(RIGHT_MOTOR_PORT,RIGHT_MOTOR_A_PIN,LOW);
			MDIO_voidWrite_D_pin(RIGHT_MOTOR_PORT,RIGHT_MOTOR_B_PIN,LOW);
			break;

		case MOTOR_LEFT:
			MDIO_voidWrite_D_pin(LEFT_MOTOR_PORT,LEFT_MOTOR_A_PIN,LOW);
			MDIO_voidWrite_D_pin(LEFT_MOTOR_PORT,LEFT_MOTOR_B_PIN,LOW);
			break;
		}
}

void HBMOTORS_voidSetSpeed(uint8 Copy_uint8MotorNO,uint8 Copy_uint8Speed){
	switch(Copy_uint8MotorNO){
	case MOTOR_RIGHT:
		MTIMER_SetPwm_CH_DutyCycle(Copy_uint8Speed,TIMER_3,CHANNEL_1);
		break;
	case MOTOR_LEFT:
		MTIMER_SetPwm_CH_DutyCycle(Copy_uint8Speed,TIMER_3,CHANNEL_2);
		break;
	}

}


uint32 HBMOTORS_uint32GetSpeed(uint8 Copy_uint8MotorNO){
	uint32 Local_uint32FirstReading,Local_uint32SecondReading;
	switch(Copy_uint8MotorNO){
		case MOTOR_RIGHT:
			Local_uint32FirstReading=MTimer_uint32GetPulseTime(TIMER_2,CHANNEL_1);
			Local_uint32SecondReading=MTimer_uint32GetPulseTime(TIMER_2,CHANNEL_1);
			return Local_uint32SecondReading;
			break;
		case MOTOR_LEFT:
			Local_uint32FirstReading=MTimer_uint32GetPulseTime(TIMER_2,CHANNEL_2);
			Local_uint32SecondReading=MTimer_uint32GetPulseTime(TIMER_2,CHANNEL_2);
			return (1/((Local_uint32FirstReading-Local_uint32SecondReading)*(0.000001)));
			break;
		}
}
